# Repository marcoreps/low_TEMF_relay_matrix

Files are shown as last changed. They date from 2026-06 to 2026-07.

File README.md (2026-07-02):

# low_TEMF_relay_matrix

A low-thermal EMF relay matrix board designed for **automated 4-wire resistance measurements** and **NBS 430 voltage supervision**. Needs 5V supply and an external microcontroller to feed data into a shift register bucket brigade. Oblong terminal pads for cable shoes or brinding posts. <19" wide board for possible rack installation.

---

## Changelog

### Version 0.5
* Exposed GND copper plane around a mounting hole for convenient shield/enclosure chassis connection
* Criss-cross pattern on layers 2,3 instead of identical traces to minimize path resistance

### Version 0.4
* Symmetric annotations
* Added test points connected directly to the four buses
* Added silkscreen logos

---

## Recommended PCB

* 4 layer
* OSP (a bit difficult to strip but gives bare copper pads)
* Gold plating shouldn't be much worse

---

## Images

<div align="center">

### Overview
| 3D Render | Concept |
| :---: | :---: |
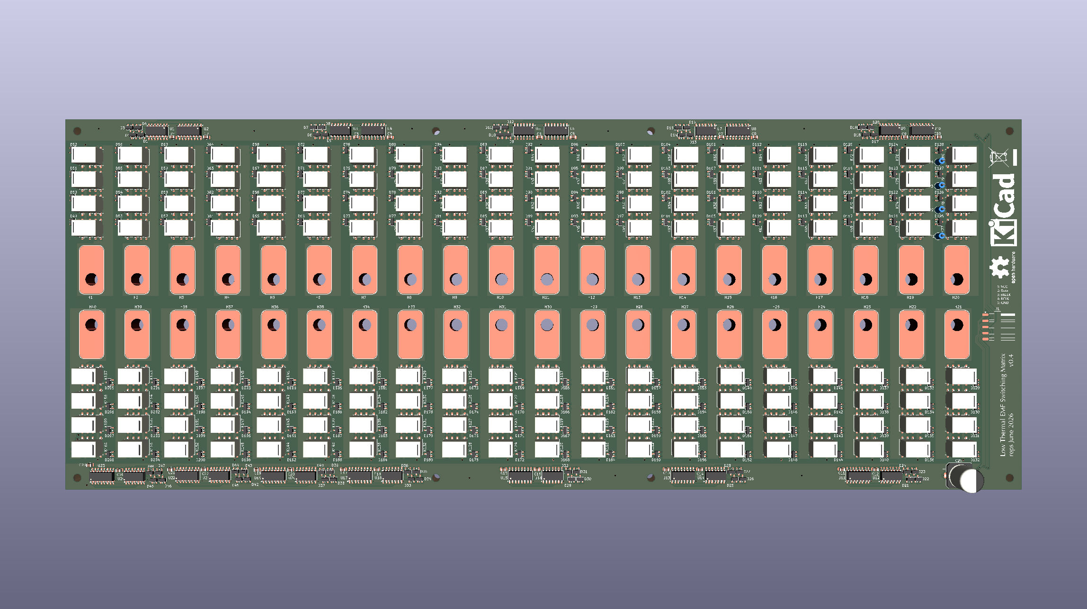
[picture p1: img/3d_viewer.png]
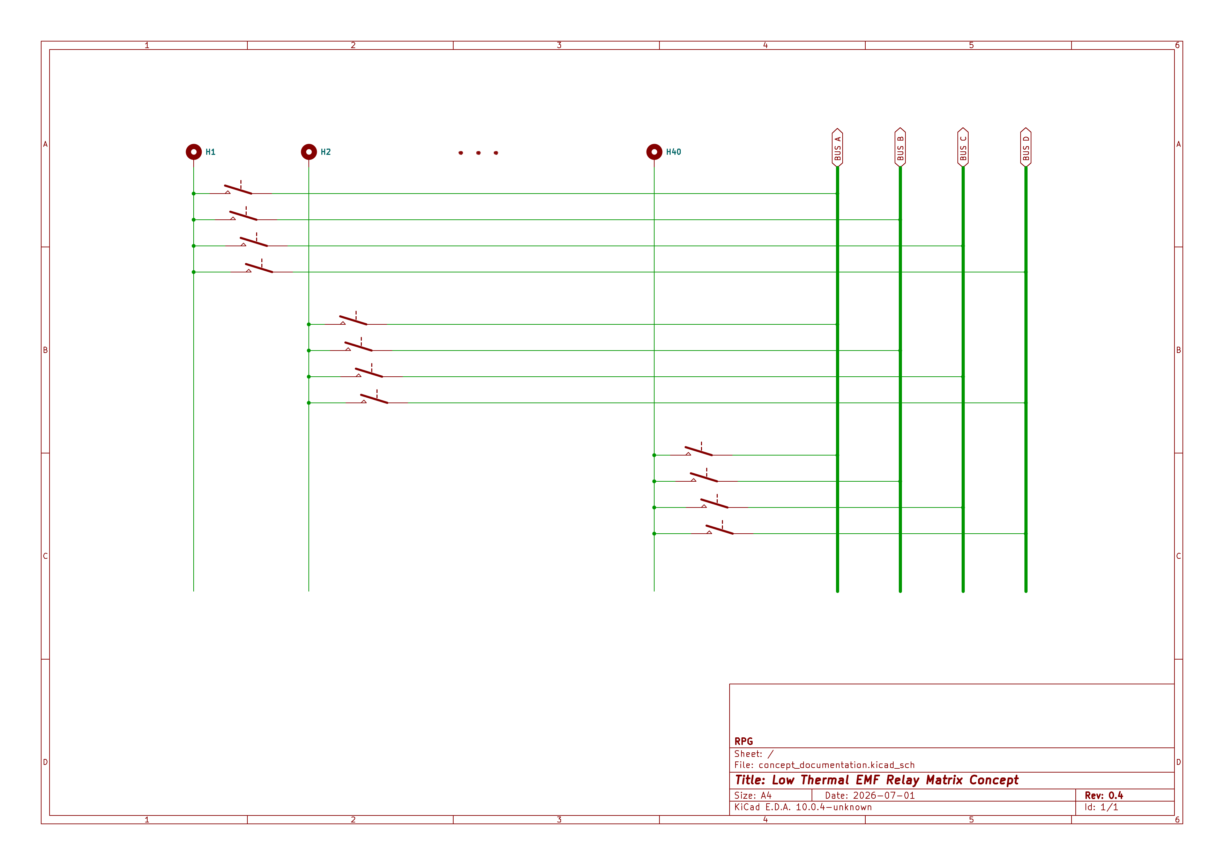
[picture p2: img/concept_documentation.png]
|  |  |

### Schematics
| Relay Driver | Relay Block |
| :---: | :---: |
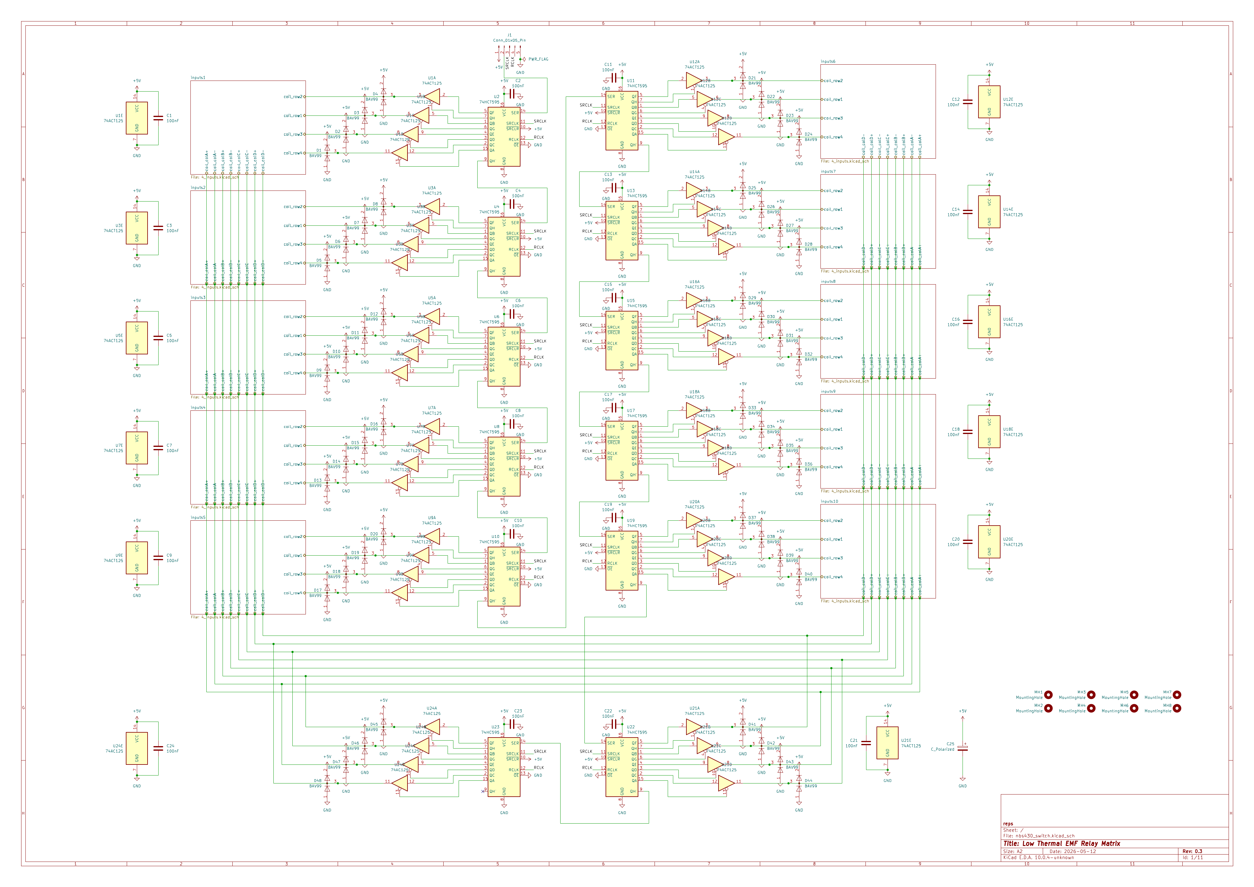
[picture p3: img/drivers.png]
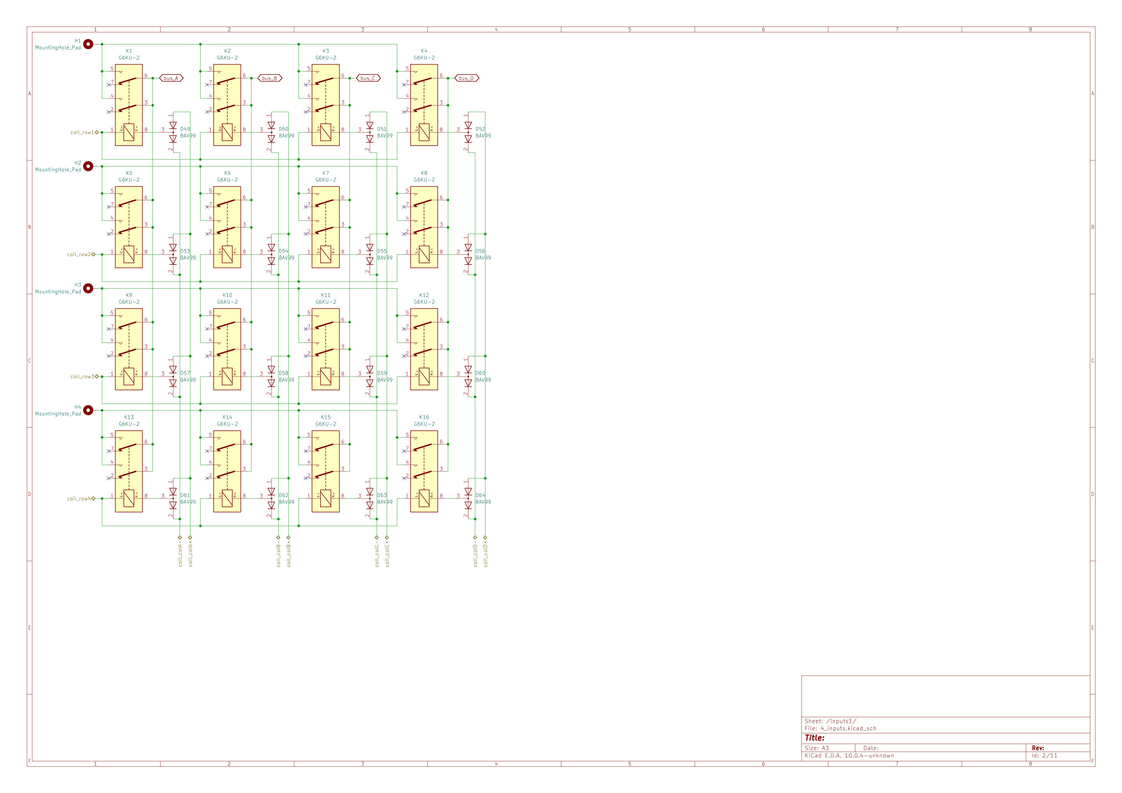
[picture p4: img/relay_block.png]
|  |  |

### Performance
| Test Results of 0.4|
| :---: |
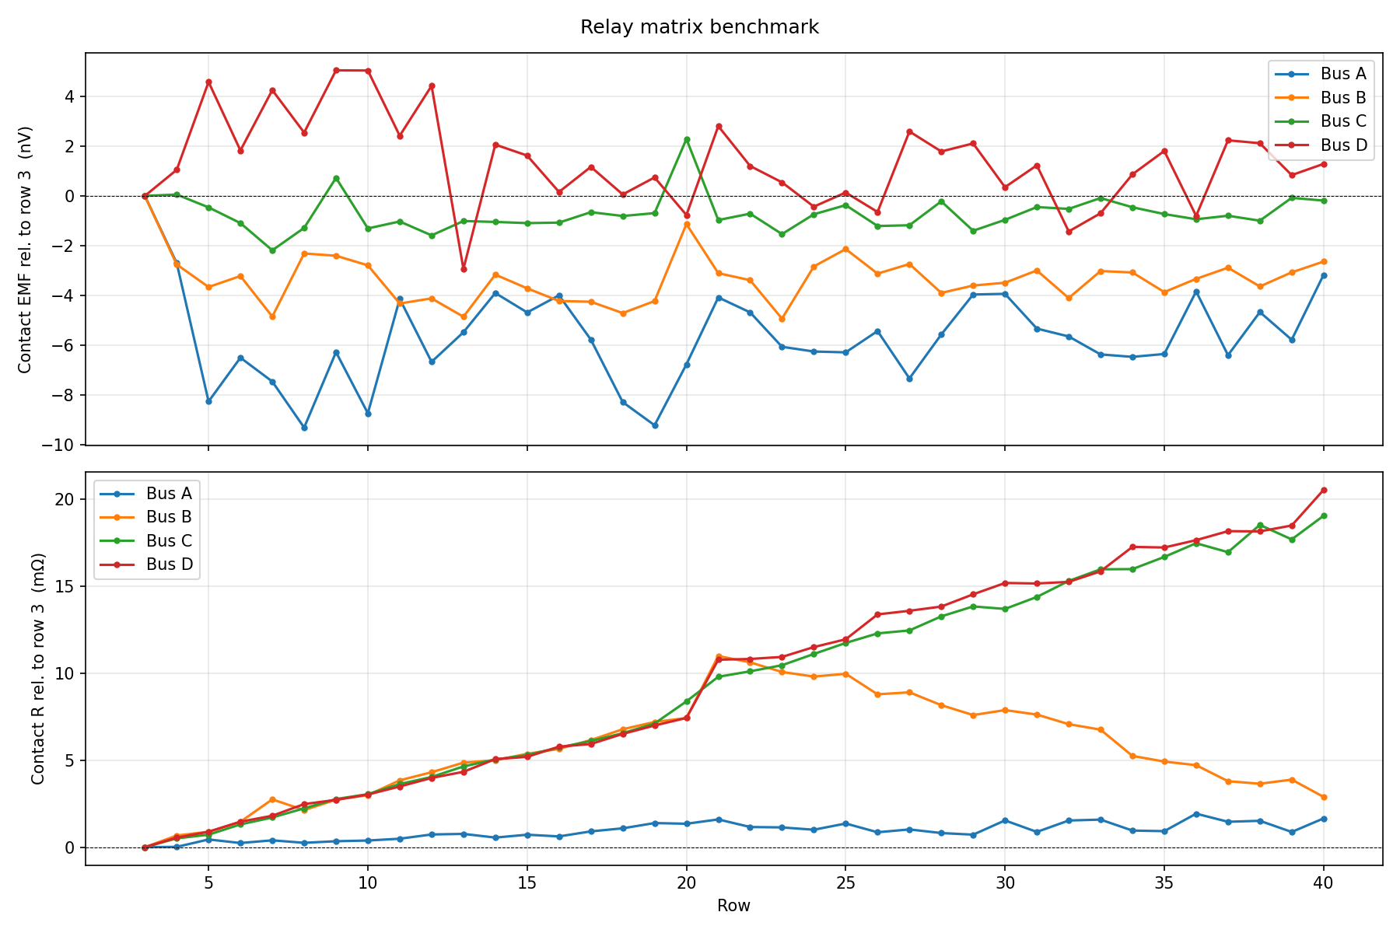
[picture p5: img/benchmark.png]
|  |

### Heat spreader example
| Front | Rear | Sandwitch |
| :---: | :---: | :---: |
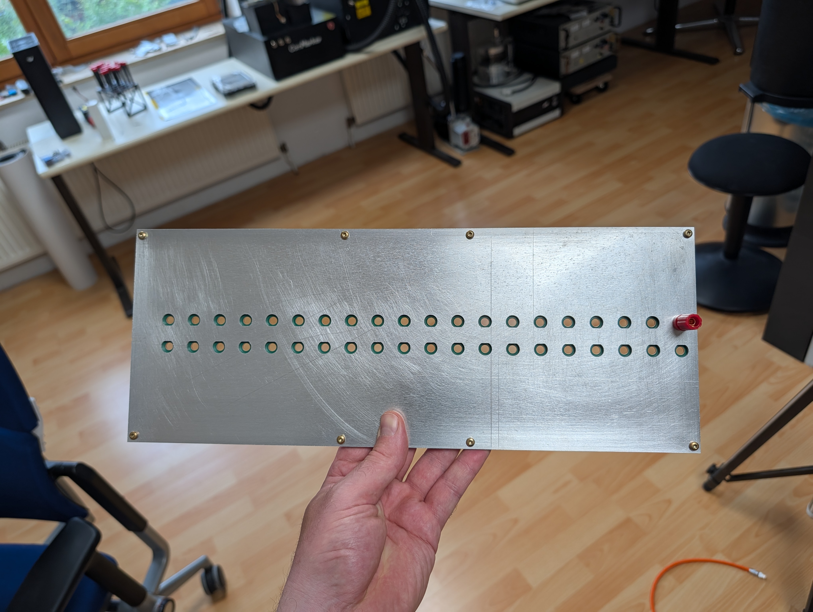
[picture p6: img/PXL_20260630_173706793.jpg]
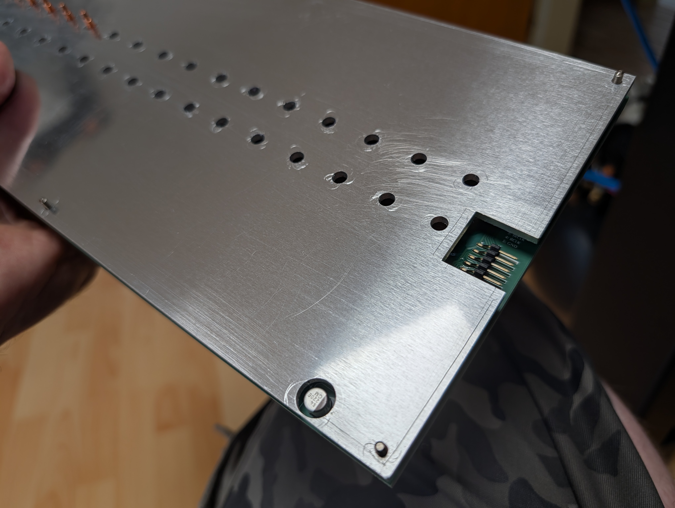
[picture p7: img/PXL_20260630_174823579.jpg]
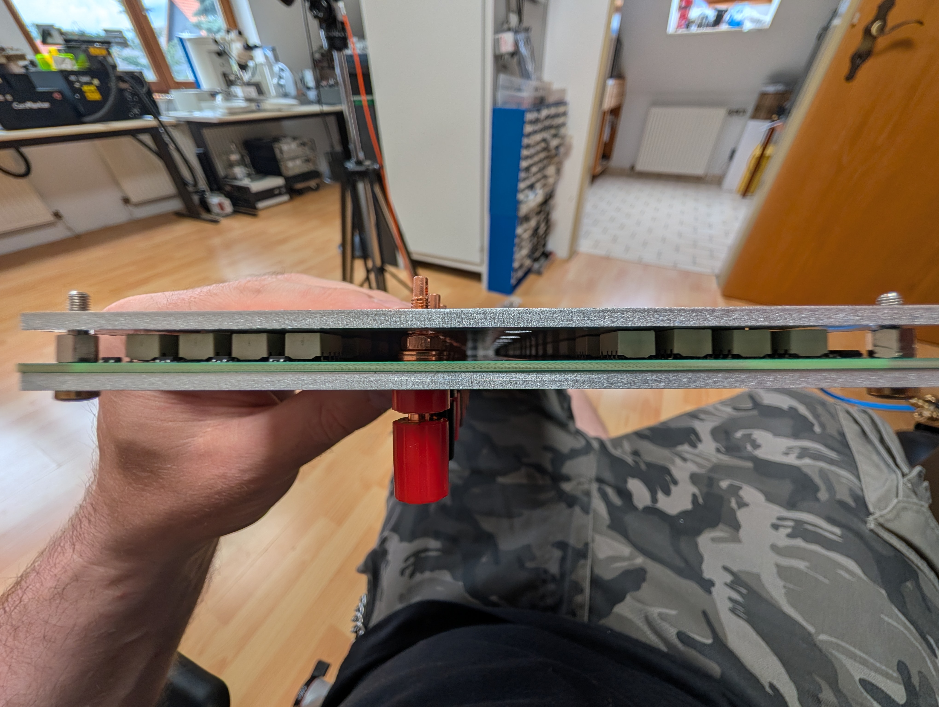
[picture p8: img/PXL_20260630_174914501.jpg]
|  |  |  |

| Taobao Terminals | 3mm Al plate | 19" width |
| :---: | :---: | :---: |
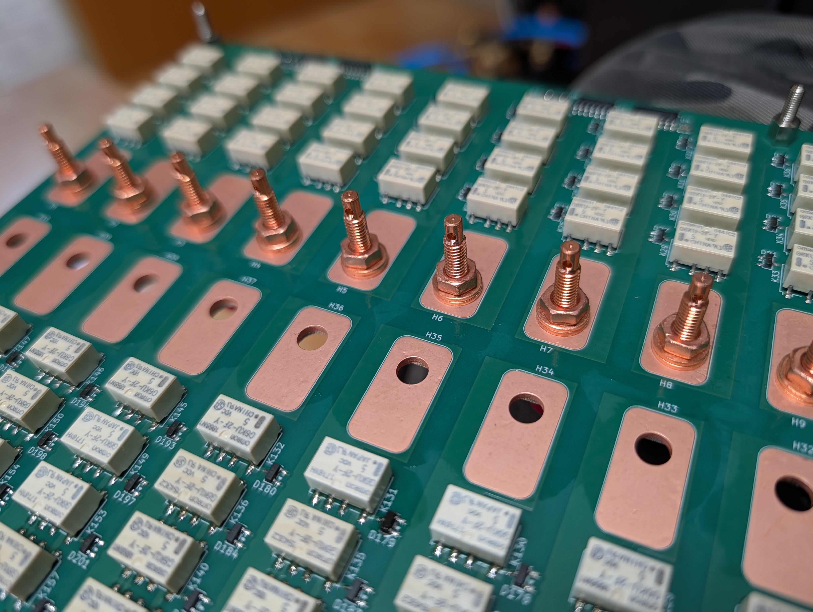
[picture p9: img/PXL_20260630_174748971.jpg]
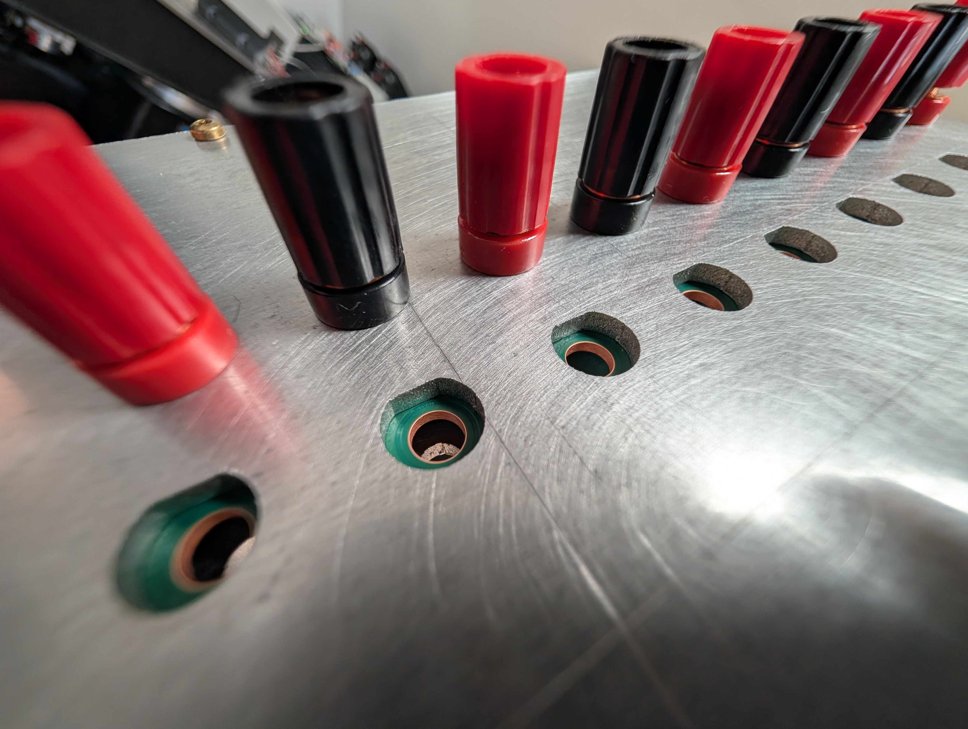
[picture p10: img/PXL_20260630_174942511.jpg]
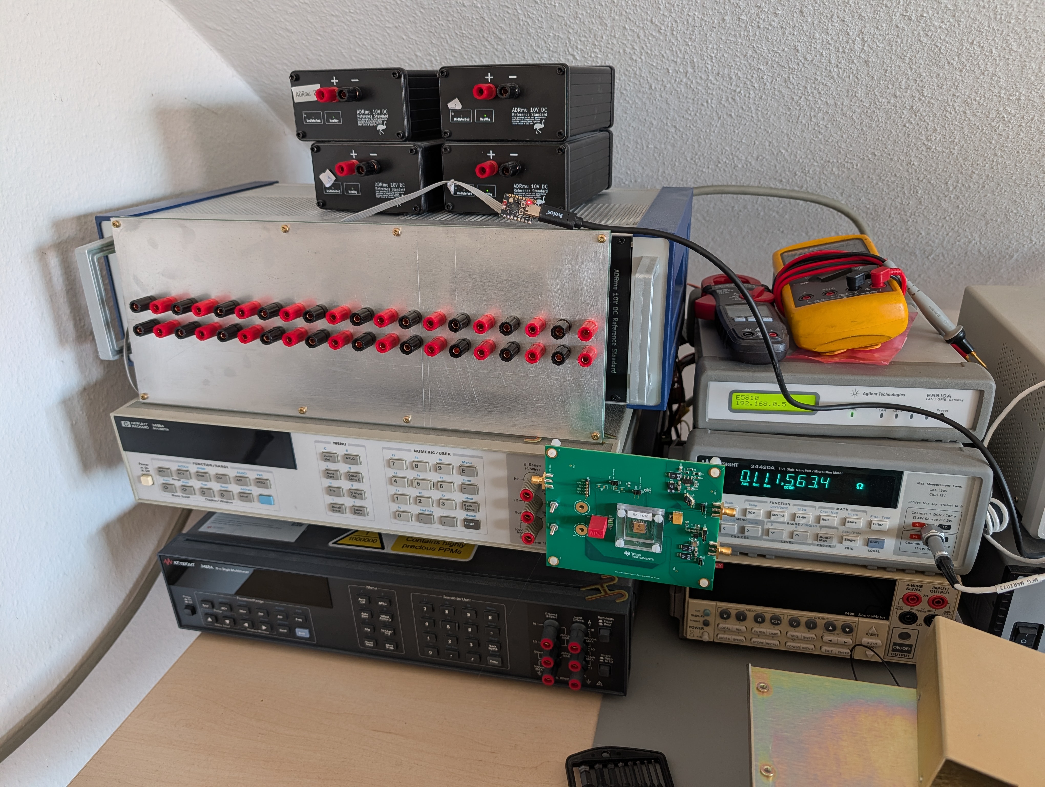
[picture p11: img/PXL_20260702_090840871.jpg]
|  |  |  |

</div>

---

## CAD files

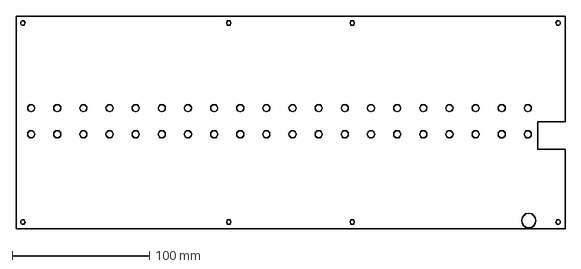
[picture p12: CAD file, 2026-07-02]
cad/rear_plate_cutting_pattern.dxf
400.0 x 155.0 mm

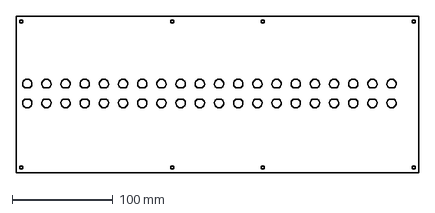
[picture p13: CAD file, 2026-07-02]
cad/front_plate_cutting_pattern.dxf
400.0 x 155.0 mm

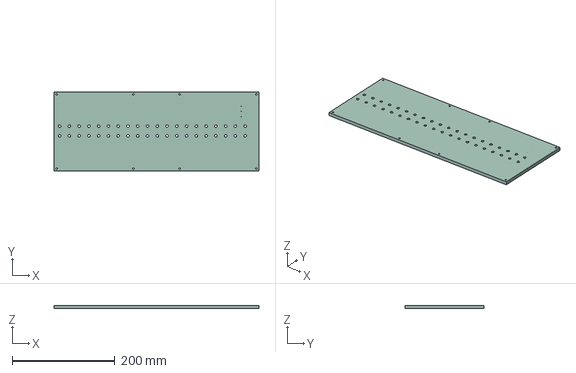
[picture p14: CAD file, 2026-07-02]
cad/pcb.step
400.0 x 155.0 x 6.21 mm

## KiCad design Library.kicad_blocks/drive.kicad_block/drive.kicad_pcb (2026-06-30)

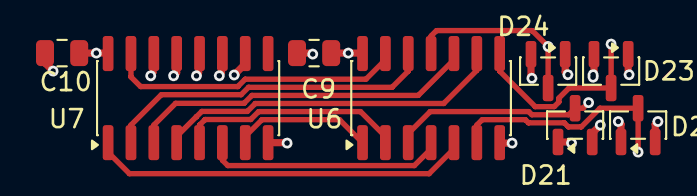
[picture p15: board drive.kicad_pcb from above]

Board: 4 copper layers, 8 parts (0 on the bottom side), 14 nets.

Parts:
C9, C10: 100nF; C_0805_2012Metric
D21, D22, D23, D24: BAV99; SOT-23
U6: 74AC125; SOIC-14_3.9x8.7mm_P1.27mm
U7: 74HC595; SOIC-16_3.9x9.9mm_P1.27mm

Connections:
+3.3V: C9.2, C10.2, D21.2 (A), D22.2 (A), D23.2 (A), D24.2 (A), U6.14 (VCC), U7.10 (~SRCLR), U7.16 (VCC)
/inputs6/coil_row1: D22.3 (K), U6.6
/inputs6/coil_row2: D21.3 (K), U6.3
/inputs6/coil_row3: D23.3 (K), U6.8
/inputs6/coil_row4: D24.3 (K), U6.11
GND: C9.1, C10.1, D21.1 (K), D22.1 (K), D23.1 (K), D24.1 (K), U6.7 (GND), U7.8 (GND), U7.13 (~OE)
unnamed: U6.13, U7.15 (QA)
unnamed: U6.5, U7.1 (QB)
unnamed: U6.12, U7.2 (QC)
unnamed: U6.10, U7.3 (QD)
unnamed: U6.9, U7.4 (QE)
unnamed: U6.2, U7.5 (QF)
unnamed: U6.4, U7.6 (QG)
unnamed: U6.1, U7.7 (QH)

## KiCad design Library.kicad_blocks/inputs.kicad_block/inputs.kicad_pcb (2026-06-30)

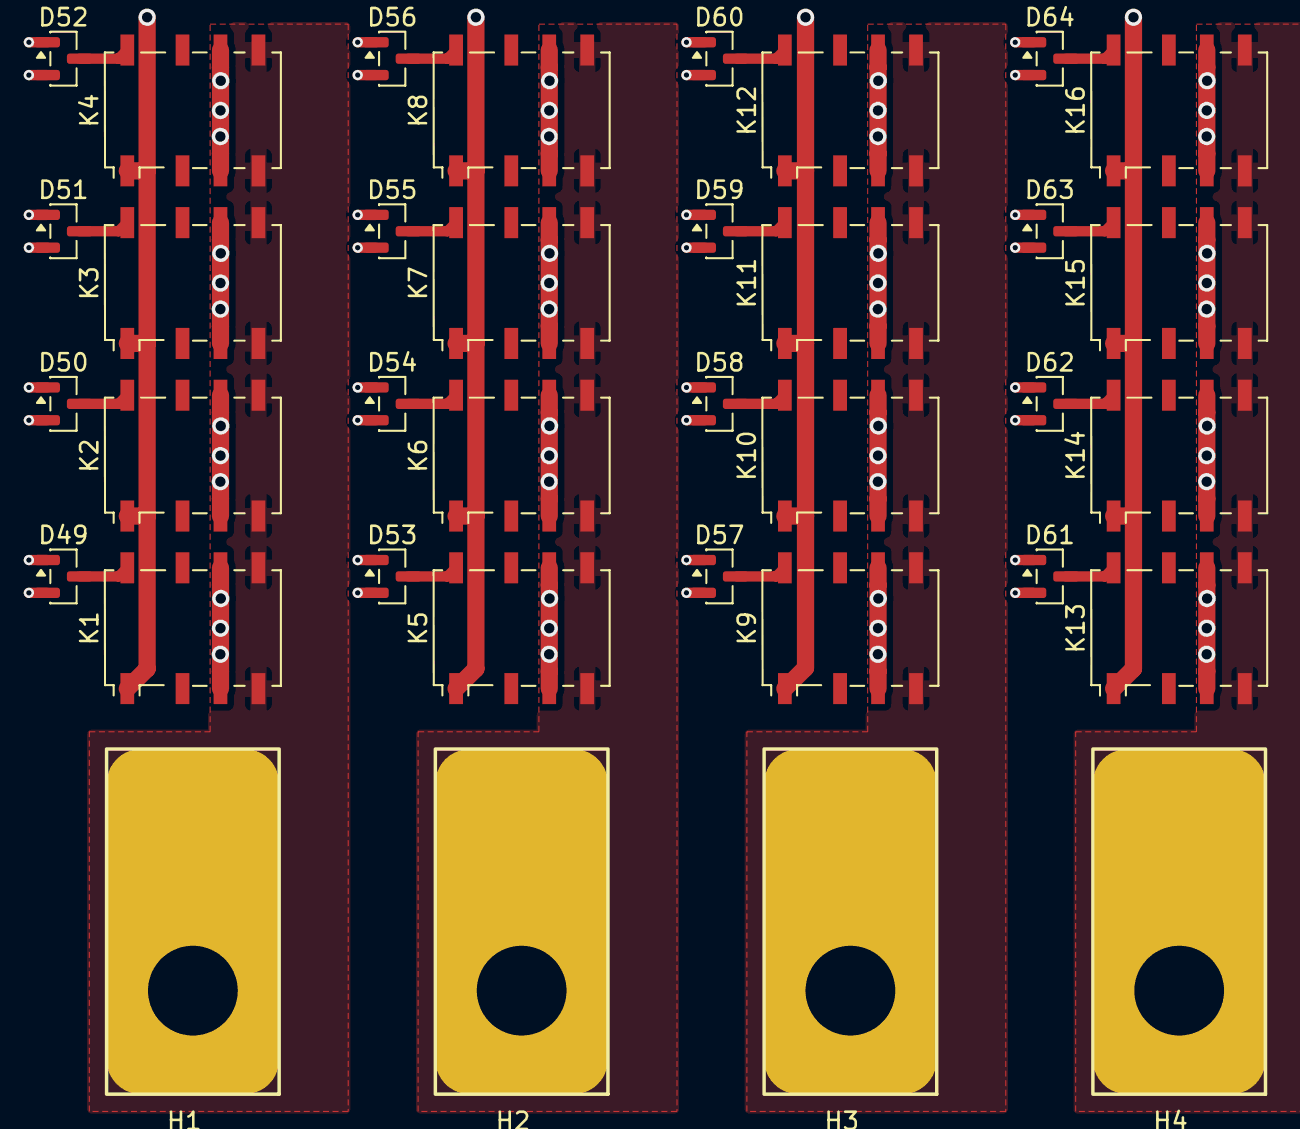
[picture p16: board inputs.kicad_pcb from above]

Board: 4 copper layers, 36 parts (0 on the bottom side), 36 nets.

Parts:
D49, D50, D51, D52, D53, D54, D55, D56, D57, D58, D59, D60, D61, D62, D63, D64: BAV99; SOT-23
H1, H2, H3, H4: MountingHole_Pad; MountingHole_large_Pad
K1, K2, K3, K4, K5, K6, K7, K8, K9, K10, K11, K12, K13, K14, K15, K16: G6KU-2; Relay_DPDT_Omron_G6K-2F-Y

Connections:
/inputs1/coil_colA+: D49.1 (K), D53.1 (K), D57.1 (K), D61.1 (K)
/inputs1/coil_colA-: D49.2 (A), D53.2 (A), D57.2 (A), D61.2 (A)
/inputs1/coil_colB+: D50.1 (K), D54.1 (K), D58.1 (K), D62.1 (K)
/inputs1/coil_colB-: D50.2 (A), D54.2 (A), D58.2 (A), D62.2 (A)
/inputs1/coil_colC+: D51.1 (K), D55.1 (K), D59.1 (K), D63.1 (K)
/inputs1/coil_colC-: D51.2 (A), D55.2 (A), D59.2 (A), D63.2 (A)
/inputs1/coil_colD+: D52.1 (K), D56.1 (K), D60.1 (K), D64.1 (K)
/inputs1/coil_colD-: D52.2 (A), D56.2 (A), D60.2 (A), D64.2 (A)
/inputs1/coil_row1: K1.1, K2.1, K3.1, K4.1
/inputs1/coil_row2: K5.1, K6.1, K7.1, K8.1
/inputs1/coil_row3: K9.1, K10.1, K11.1, K12.1
/inputs1/coil_row4: K13.1, K14.1, K15.1, K16.1
unnamed: D49.3 (K), K1.8
unnamed: D50.3 (K), K2.8
unnamed: D51.3 (K), K3.8
unnamed: D52.3 (K), K4.8
unnamed: D53.3 (K), K5.8
unnamed: D54.3 (K), K6.8
unnamed: D55.3 (K), K7.8
unnamed: D56.3 (K), K8.8
unnamed: D57.3 (K), K9.8
unnamed: D58.3 (K), K10.8
unnamed: D59.3 (K), K11.8
unnamed: D60.3 (K), K12.8
unnamed: D61.3 (K), K13.8
unnamed: D62.3 (K), K14.8
unnamed: D63.3 (K), K15.8
unnamed: D64.3 (K), K16.8
unnamed: H1.1 (1_1), K1.4, K1.5, K2.4, K2.5, K3.4, K3.5, K4.4, K4.5
unnamed: H2.1 (1_1), K5.4, K5.5, K6.4, K6.5, K7.4, K7.5, K8.4, K8.5
unnamed: H3.1 (1_1), K9.4, K9.5, K10.4, K10.5, K11.4, K11.5, K12.4, K12.5
unnamed: H4.1 (1_1), K13.4, K13.5, K14.4, K14.5, K15.4, K15.5, K16.4, K16.5
bus_A: K1.3, K1.6, K5.3, K5.6, K9.3, K9.6, K13.3, K13.6
bus_B: K2.3, K2.6, K6.3, K6.6, K10.3, K10.6, K14.3, K14.6
bus_C: K3.3, K3.6, K7.3, K7.6, K11.3, K11.6, K15.3, K15.6
bus_D: K4.3, K4.6, K8.3, K8.6, K12.3, K12.6, K16.3, K16.6

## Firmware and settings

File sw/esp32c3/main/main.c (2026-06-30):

#include <stdio.h>
#include <string.h>
#include <ctype.h>
#include <stdbool.h>
#include "freertos/FreeRTOS.h"
#include "freertos/task.h"
#include "driver/spi_master.h"
#include "driver/gpio.h"
#include "esp_log.h"
#include "esp_timer.h"

static const char *TAG = "MATRIX_CTRL";

// Hardware Pin Definitions
#define PIN_NUM_MISO -1
#define PIN_NUM_MOSI GPIO_NUM_3  // DATA
#define PIN_NUM_CLK  GPIO_NUM_1  // SRCLK
#define PIN_NUM_LATCH GPIO_NUM_0 // RCLK

// Matrix Configuration
#define NUM_SHIFT_REGS 12        // 10 for rows, 2 for columns
#define PULSE_DURATION_uS 1000     // Choose minimal reliable value

// Lets abuse SPI for shifting out data
spi_device_handle_t spi;

// Array to hold all outgoing bits
uint8_t sr_data[NUM_SHIFT_REGS];

void fast_boot_flush(void);
void init_hardware(void);
void clear_shift_registers(void);
void update_shift_registers(void);
void set_driver(uint8_t sr_index, uint8_t driver_idx, bool enable_driver, bool control_high);
void process_command(const char* cmd);

void console_rx_task(void *pvParameters);

void app_main(void) {
    fast_boot_flush();
    
    ESP_LOGI(TAG, "Initializing the Matrix ...");
    init_hardware();

    clear_shift_registers();
    update_shift_registers();

    ESP_LOGI(TAG, "Matrix Ready. Listening but not mirroring ...");

    xTaskCreate(console_rx_task, "console_rx_task", 4096, NULL, 10, NULL);
}

void console_rx_task(void *pvParameters) {
    char buf[16];
    int idx = 0;

    while (1) {
        int c = getchar();

        if (c == EOF || c == 0xFF) {
            vTaskDelay(pdMS_TO_TICKS(10)); 
            continue;
        }

        if (c == '\r' || c == '\n') {
            if (idx > 0) {
                buf[idx] = '\0'; 
                
                for(int i = 0; buf[i]; i++) buf[i] = toupper((unsigned char)buf[i]);
                
                if (strlen(buf) == 4)
                    process_command(buf);
                else
                    ESP_LOGE(TAG, "Command '%s' invalid. Must be exactly 4 characters.", buf);
                idx = 0; 
            }
        } 
        else if (idx < sizeof(buf) - 1)
            buf[idx++] = c;
    }
}

void fast_boot_flush(void) {
    gpio_set_direction(PIN_NUM_MOSI, GPIO_MODE_OUTPUT);
    gpio_set_direction(PIN_NUM_CLK, GPIO_MODE_OUTPUT);
    gpio_set_direction(PIN_NUM_LATCH, GPIO_MODE_OUTPUT);

    gpio_set_level(PIN_NUM_LATCH, 0);
    gpio_set_level(PIN_NUM_MOSI, 1);
    
    // Flushes the bucket brigade to guarantee all shift registers are packed with 1s
    for (int i = 0; i < 100; i++) {
        gpio_set_level(PIN_NUM_CLK, 1);
        esp_rom_delay_us(1);
        gpio_set_level(PIN_NUM_CLK, 0);
        esp_rom_delay_us(1);
    }
    
    gpio_set_level(PIN_NUM_LATCH, 1);
}

void init_hardware(void) {
    spi_bus_config_t buscfg = {
        .miso_io_num = PIN_NUM_MISO,
        .mosi_io_num = PIN_NUM_MOSI,
        .sclk_io_num = PIN_NUM_CLK,
        .quadwp_io_num = -1,
        .quadhd_io_num = -1,
        .max_transfer_sz = 32 
    };
    
    spi_device_interface_config_t devcfg = {
        .clock_speed_hz = 100 * 1000, // with 96 kHz we could still get 1ms pulses on any pin
        .mode = 0,
        .spics_io_num = -1,
        .queue_size = 1,
    };

    ESP_ERROR_CHECK(spi_bus_initialize(SPI2_HOST, &buscfg, SPI_DMA_DISABLED));
    ESP_ERROR_CHECK(spi_bus_add_device(SPI2_HOST, &devcfg, &spi));
}

void set_driver(uint8_t sr_index, uint8_t driver_index, bool enable_driver, bool control_high) {
    uint8_t sleep_bit, control_bit;
    
    switch(driver_index) {
        case 0: sleep_bit = 6; control_bit = 1; break; // Driver 1: QG/QB
        case 1: sleep_bit = 7; control_bit = 5; break; // Driver 2: QH/QF
        case 2: sleep_bit = 3; control_bit = 4; break; // Driver 3: QD/QE
        case 3: sleep_bit = 0; control_bit = 2; break; // Driver 4: QA/QC
        default: return;
    }

    if (enable_driver)
        sr_data[sr_index] &= ~(1 << sleep_bit); // 0 = Driver Enabled
    else
        sr_data[sr_index] |=  (1 << sleep_bit); // probably never needed but eh

    if (control_high)
        sr_data[sr_index] |=  (1 << control_bit);
    else
        sr_data[sr_index] &= ~(1 << control_bit);
}

void process_command(const char* cmd) {
    int row = (cmd[0] - '0') * 10 + (cmd[1] - '0');
    char col_char = cmd[2];
    char flip_char = cmd[3];
    
    if (row < 1 || row > 40) {
        ESP_LOGE(TAG, "Row error. Must be 01-40.");
        return;
    }

    int col_idx = 0;
    if (col_char >= 'A' && col_char <= 'D')
        col_idx = col_char - 'A';
    else {
        ESP_LOGE(TAG, "Column error. Must be A-D.");
        return;
    }

    bool do_flip = false;
    if (flip_char == '1')
        do_flip = true;
    else if (flip_char == '0')
        do_flip = false;
    else {
        ESP_LOGE(TAG, "Action error. Must be 1 (close relay / connect) or 0 (open relay / disconnect).");
        return;
    }

    int row_idx = row - 1; 
    int row_sr_index = row_idx / 4; 
    int row_driver = row_idx % 4;


    const uint8_t col_plus_sr[4]   = {10, 11, 10, 11};
    const uint8_t col_plus_drv[4]  = { 0,  1,  3,  3};
    
    const uint8_t col_minus_sr[4]  = {11, 10, 11, 10};
    const uint8_t col_minus_drv[4] = { 2,  2,  0,  1};

    ESP_LOGI(TAG, "Executing: Row %02d, Col %c, Action: %s", row, col_char, do_flip ? "FLIP" : "DE-FLIP");

    clear_shift_registers(); 

    if (do_flip) {
        // FLIP: Row acts as source, Column Minus acts as sink
        set_driver(row_sr_index, row_driver, true, true);
        set_driver(col_minus_sr[col_idx], col_minus_drv[col_idx], true, false);
    } else {
        // DE-FLIP: Column Plus acts as source, Row acts as sink
        set_driver(row_sr_index, row_driver, true, false);
        set_driver(col_plus_sr[col_idx], col_plus_drv[col_idx], true, true);
    }

    update_shift_registers(); 

    // Pulse duration
    esp_rom_delay_us(PULSE_DURATION_uS);

    // Isolate everybody
    clear_shift_registers();    
    update_shift_registers();   

    ESP_LOGI(TAG, "Pulse Complete.");
}

void clear_shift_registers(void) {
    memset(sr_data, 0xC9, sizeof(sr_data));
}

void update_shift_registers(void) {
    uint8_t tx_buffer[NUM_SHIFT_REGS];
    
    for (int i = 0; i < NUM_SHIFT_REGS; i++) {
        tx_buffer[i] = sr_data[NUM_SHIFT_REGS - 1 - i];
    }

    spi_transaction_t t = {
        .length = NUM_SHIFT_REGS * 8, 
        .tx_buffer = tx_buffer,
    };

    gpio_set_level(PIN_NUM_LATCH, 0);
    ESP_ERROR_CHECK(spi_device_transmit(spi, &t));
    gpio_set_level(PIN_NUM_LATCH, 1);
}

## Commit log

2026-06-30 improved annotations
    [4_inputs.kicad_sch]
2026-06-30 Added bus test points
    [4_inputs.kicad_sch, nbs430_switch.kicad_sch]
2026-06-30 addes esp32c3 firmware
2026-07-02 Rev 0.5 board
